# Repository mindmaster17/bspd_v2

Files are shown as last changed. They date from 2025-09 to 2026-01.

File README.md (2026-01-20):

# Team Petronarc GECT
# bspd_v1
# BSPD_V1 — Brake System Plausibility Device (Formula Imperial CV)

This repository contains the circuit design, schematics, and documentation for **BSPD_V1**, a low-cost and rule-compliant Brake System Plausibility Device (BSPD) designed for **Formula Imperial Combustion (CV)** vehicles using **mechanical throttle**.

---
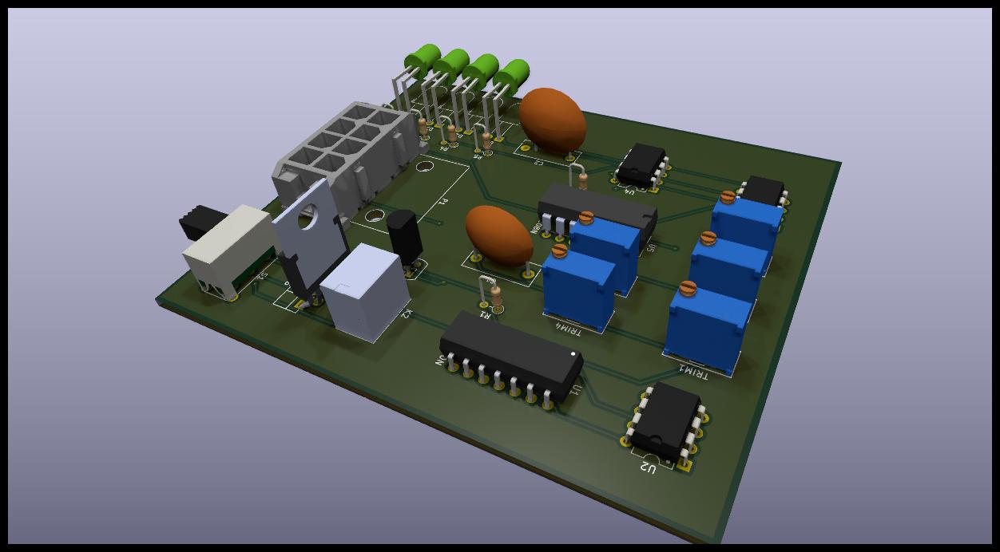
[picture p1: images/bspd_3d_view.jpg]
BSPD 3D View
|  | 3D view of the BSPD PCB assembly (component placement & enclosure layout) |

##  Overview

The **Brake System Plausibility Device (BSPD)** monitors the **Throttle Position Sensor (TPS)** and **Brake Pressure Sensor (BPS)** to detect unsafe driving conditions — specifically, **when the throttle is open beyond a limit while the brake is applied**.

If such a condition persists for more than a preset time (≈500 ms), the BSPD **opens the shutdown circuit**, cutting engine power (via the fuel pump or ECU relay).

This design follows the **Formula Imperial 2025 Rulebook (E.2.9)** guidelines for CV vehicles.

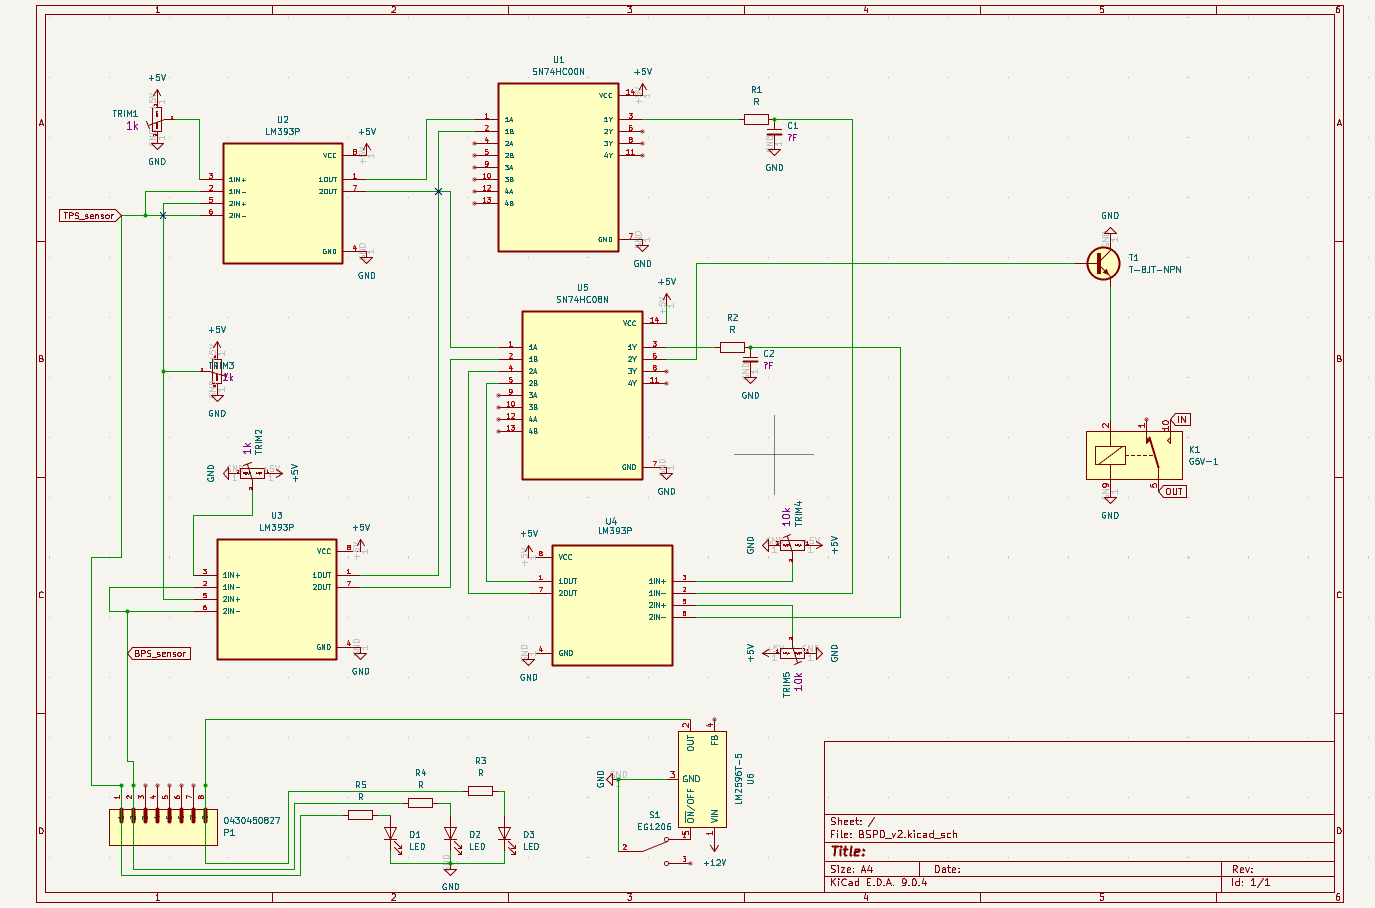
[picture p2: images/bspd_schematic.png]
BSPD Schematic Diagram
|  | Electrical schematic showing comparators, thresholds, latch, and relay driver stages |
---

##  Key Features

- ✅ **2 Analog Inputs** — Throttle (0–5 V) and Brake (0–5 V or 0–10 V)
- ✅ **Adjustable Thresholds** for both BPS and TPS (via onboard potentiometers)
- ✅ **Plausibility Delay:** ~0.5 s (adjustable via RC network)
- ✅ **Latch on Fault:** Once tripped, BSPD remains in fault state until the **Primary Master Switch (PMS)** is cycled
- ✅ **Onboard Indicators:** LEDs for Brake threshold, Throttle threshold, and Fault
- ✅ **12 V operation (8–24 V range)** with onboard 5 V regulation
- ✅ **Fail-Safe Relay Output:** Normally Closed (NC) relay for shutdown loop

---

## 🧩 How It Works

1. **TPS Comparator** checks if throttle > 10% (or > set threshold).
2. **BPS Comparator** checks if brake > set pressure (typically ≥ 30 bar).
3. Both outputs go into a **NOR gate** — if both are HIGH (throttle + brake), output triggers fault.
4. A **delay comparator (≈500 ms)** ensures it’s not a false transient.
5. **Relay driver** drops the shutdown loop (fuel pump / ECU power).
6. BSPD stays tripped until **PMS is turned OFF → ON**.

---

## 🪛 Modifications (for FI 2025 Compliance)

| Issue | Action Taken | Rule Reference |
|---|---|---|
| Auto reset after 10 s (non-compliant) | Disabled RC network (R12–C7) | FI E.2.9.5 |
| Cockpit reset not allowed | Only resets via PMS cycle | FI E.2.9.6 |
| Power always ON | BSPD powered only from PMS-switched 12 V line | FI E.2.9 |
| Plausibility logic | Verified 0.45 V – 5 V window check and 500 ms delay | FI E.2.9 |

---

## 🧰 Components

| Component | Value | Description |
|---|---|---|
| LM393 | Dual comparator | Plausibility & fault logic |
| LM7805 / LM2596 | Regulator | 12 V → 5 V logic supply |
| R12 | 100 kΩ | *Removed* to disable auto-reset |
| C7 | 100 µF | *Removed* or open-circuited |
| Relay | 12 V, SPDT, NC used for shutdown loop | Fuel/ECU cutoff |
| LEDs | — | Fault, TPS threshold, BPS threshold indicators |

---

## ⚡ Power & Wiring

```text
Battery +  → Primary Master Switch (PMS)  → Fuse  → BSPD +12 V  → Fuel Pump Relay Coil → ECU

BSPD Signal Output  →  Controls Shutdown Relay  → In series with Fuel Pump or ECU power

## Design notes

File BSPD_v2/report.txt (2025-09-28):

Warning: Width correction constrained.  The width correction value must be in the range of [0.000001 mm; 0.199999 mm] for the current design rules.
Plotted to 'C:\Users\navad\Desktop\SUPRA\bspd_v2\BSPD_v2\Gerber\BSPD_v2-F_Cu.gbr'.
Plotted to 'C:\Users\navad\Desktop\SUPRA\bspd_v2\BSPD_v2\Gerber\BSPD_v2-B_Cu.gbr'.
Plotted to 'C:\Users\navad\Desktop\SUPRA\bspd_v2\BSPD_v2\Gerber\BSPD_v2-F_Paste.gbr'.
Plotted to 'C:\Users\navad\Desktop\SUPRA\bspd_v2\BSPD_v2\Gerber\BSPD_v2-B_Paste.gbr'.
Plotted to 'C:\Users\navad\Desktop\SUPRA\bspd_v2\BSPD_v2\Gerber\BSPD_v2-F_Silkscreen.gbr'.
Plotted to 'C:\Users\navad\Desktop\SUPRA\bspd_v2\BSPD_v2\Gerber\BSPD_v2-B_Silkscreen.gbr'.
Plotted to 'C:\Users\navad\Desktop\SUPRA\bspd_v2\BSPD_v2\Gerber\BSPD_v2-F_Mask.gbr'.
Plotted to 'C:\Users\navad\Desktop\SUPRA\bspd_v2\BSPD_v2\Gerber\BSPD_v2-B_Mask.gbr'.
Plotted to 'C:\Users\navad\Desktop\SUPRA\bspd_v2\BSPD_v2\Gerber\BSPD_v2-Edge_Cuts.gbr'.
Created Gerber job file 'C:\Users\navad\Desktop\SUPRA\bspd_v2\BSPD_v2\Gerber\BSPD_v2-job.gbrjob'.
Info: Done.
Info: Done.

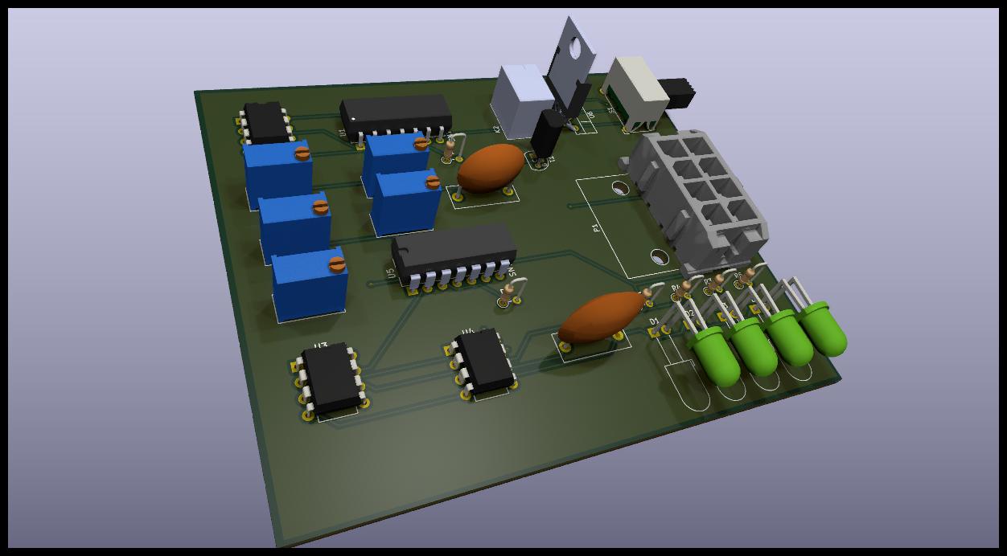
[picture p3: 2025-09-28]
images/BSPD_v2.jpg

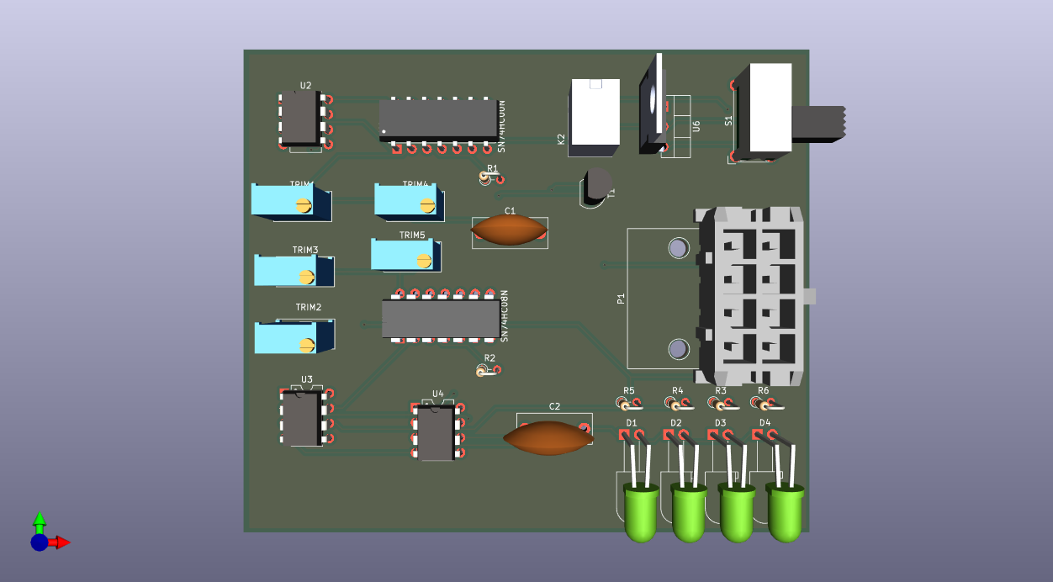
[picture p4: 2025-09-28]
images/BSPD_v2.png

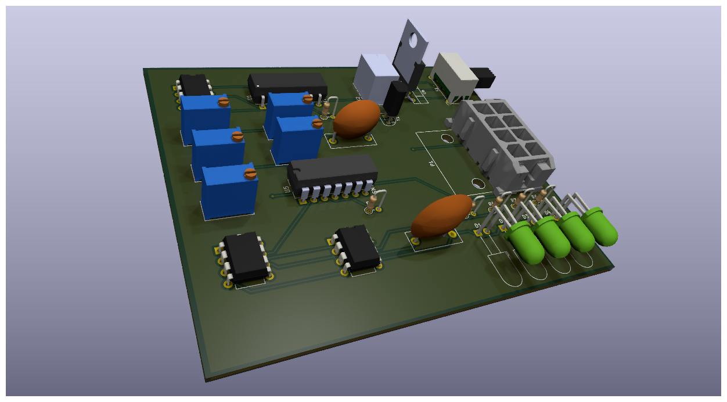
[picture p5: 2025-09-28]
BSPD_v2/BSPD_v2.png

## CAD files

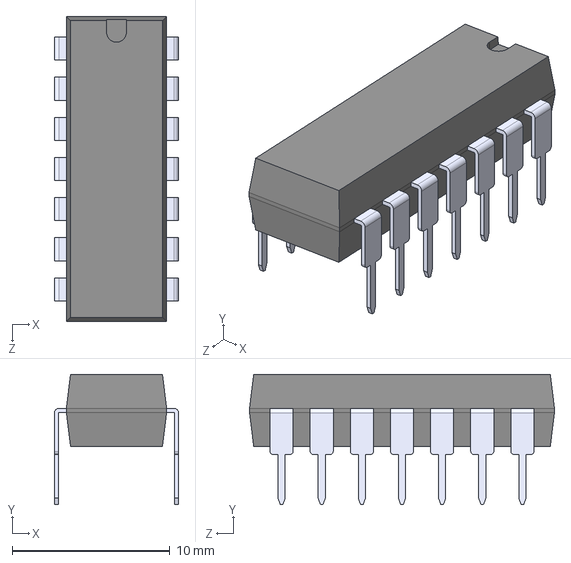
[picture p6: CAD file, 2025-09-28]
BSPD_v2/7400(NAND)/SN74HC00N.STEP
7.87 x 8.26 x 19.3 mm

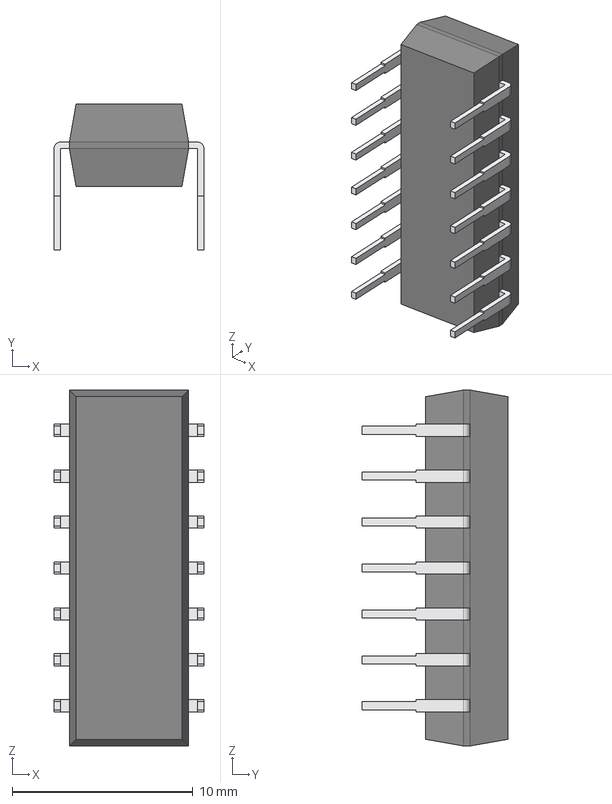
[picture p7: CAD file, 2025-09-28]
BSPD_v2/7400(NAND)/SN74HC00N/SN74HC00N.step
8.29 x 8.08 x 19.7 mm
Body001 (Mirror #1) x 8

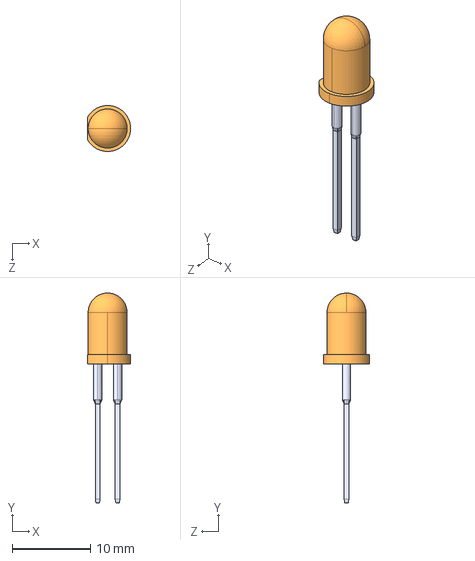
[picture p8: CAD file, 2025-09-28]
BSPD_v2/LED/L08R5000Q1--3DModel-STEP-56544.STEP
5.55 x 26.9 x 5.90 mm

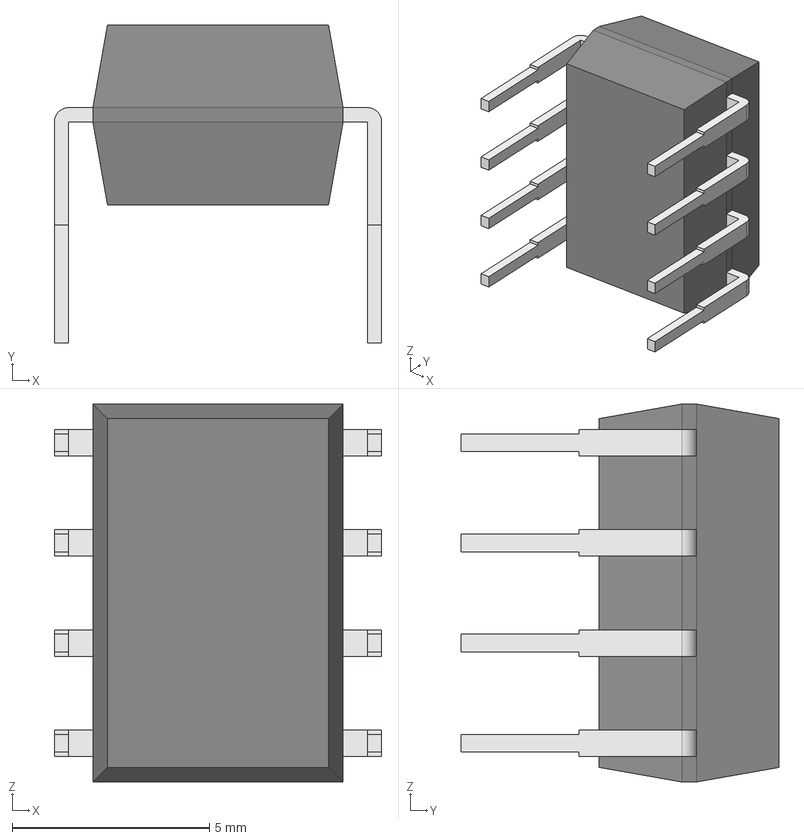
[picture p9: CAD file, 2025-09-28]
BSPD_v2/lm393/LM393P.STEP
8.31 x 8.08 x 9.59 mm
Body001 (Mirror #1) x 5

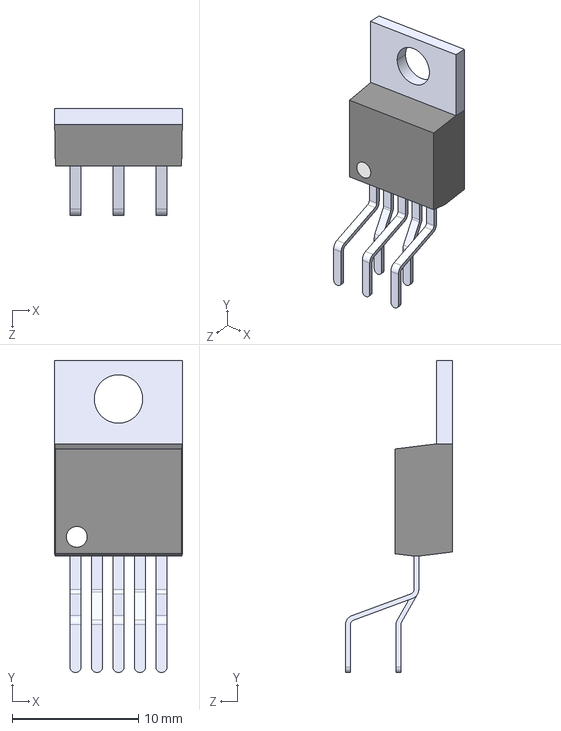
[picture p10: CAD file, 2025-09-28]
BSPD_v2/Regulator/LM2596T-5.0/LM2596T-5.0.step
10.2 x 24.7 x 8.47 mm

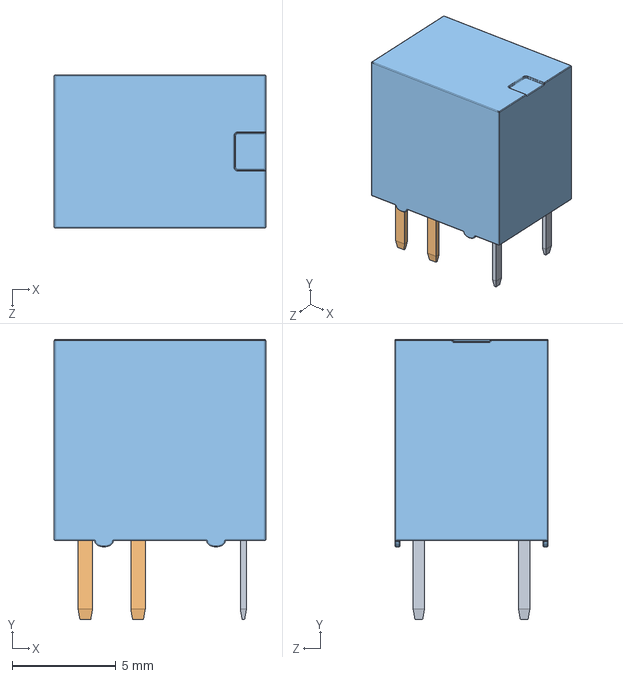
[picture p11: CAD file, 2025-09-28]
BSPD_v2/Relay/SR1-5V-450-1C--3DModel-STEP-1.STEP
10.2 x 13.5 x 7.40 mm

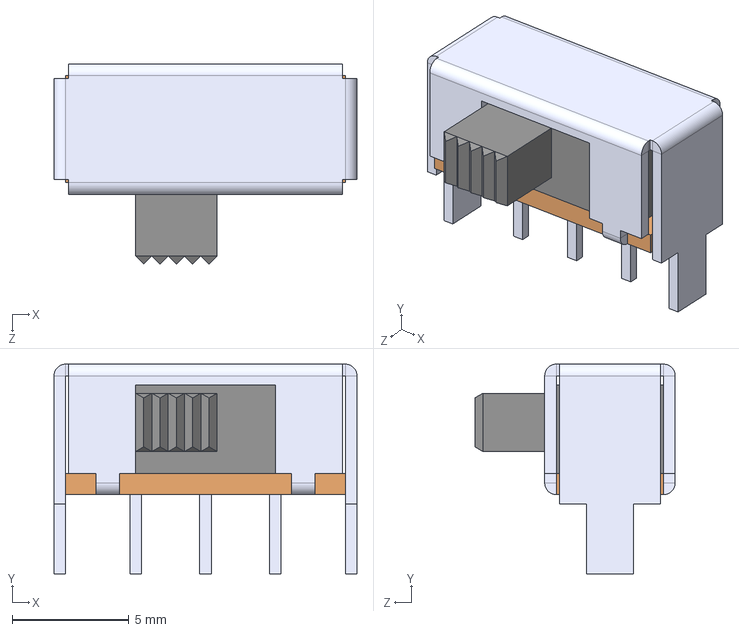
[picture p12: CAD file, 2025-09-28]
BSPD_v2/Switch/EG1206--3DModel-STEP-418109.STEP
13.0 x 9.00 x 8.60 mm

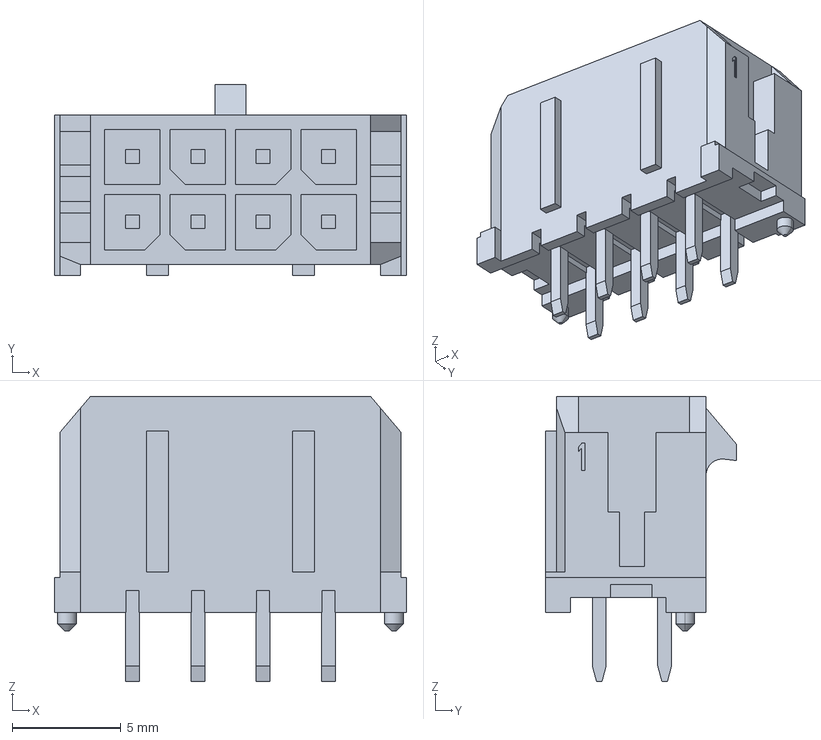
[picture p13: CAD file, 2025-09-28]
BSPD_v2/Molex_connector/0430450827/0430450827.step
16.1 x 8.77 x 13.1 mm

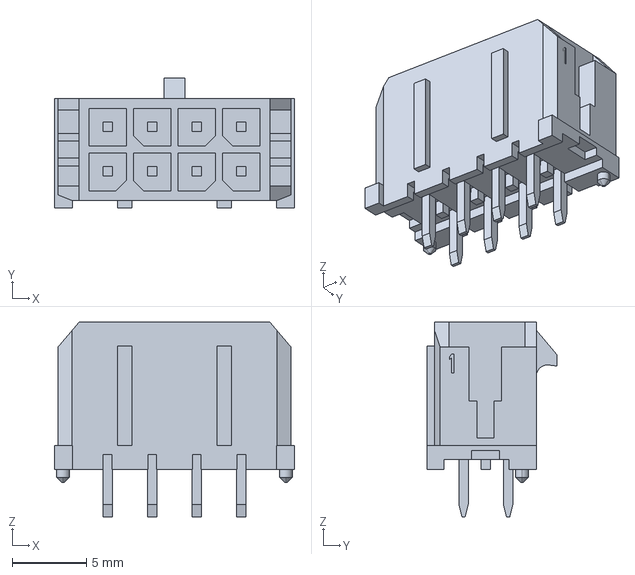
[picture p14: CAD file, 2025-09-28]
BSPD_v2/Molex_connector/171323564-659-0430450827/0430450827.stp
16.1 x 8.77 x 13.1 mm

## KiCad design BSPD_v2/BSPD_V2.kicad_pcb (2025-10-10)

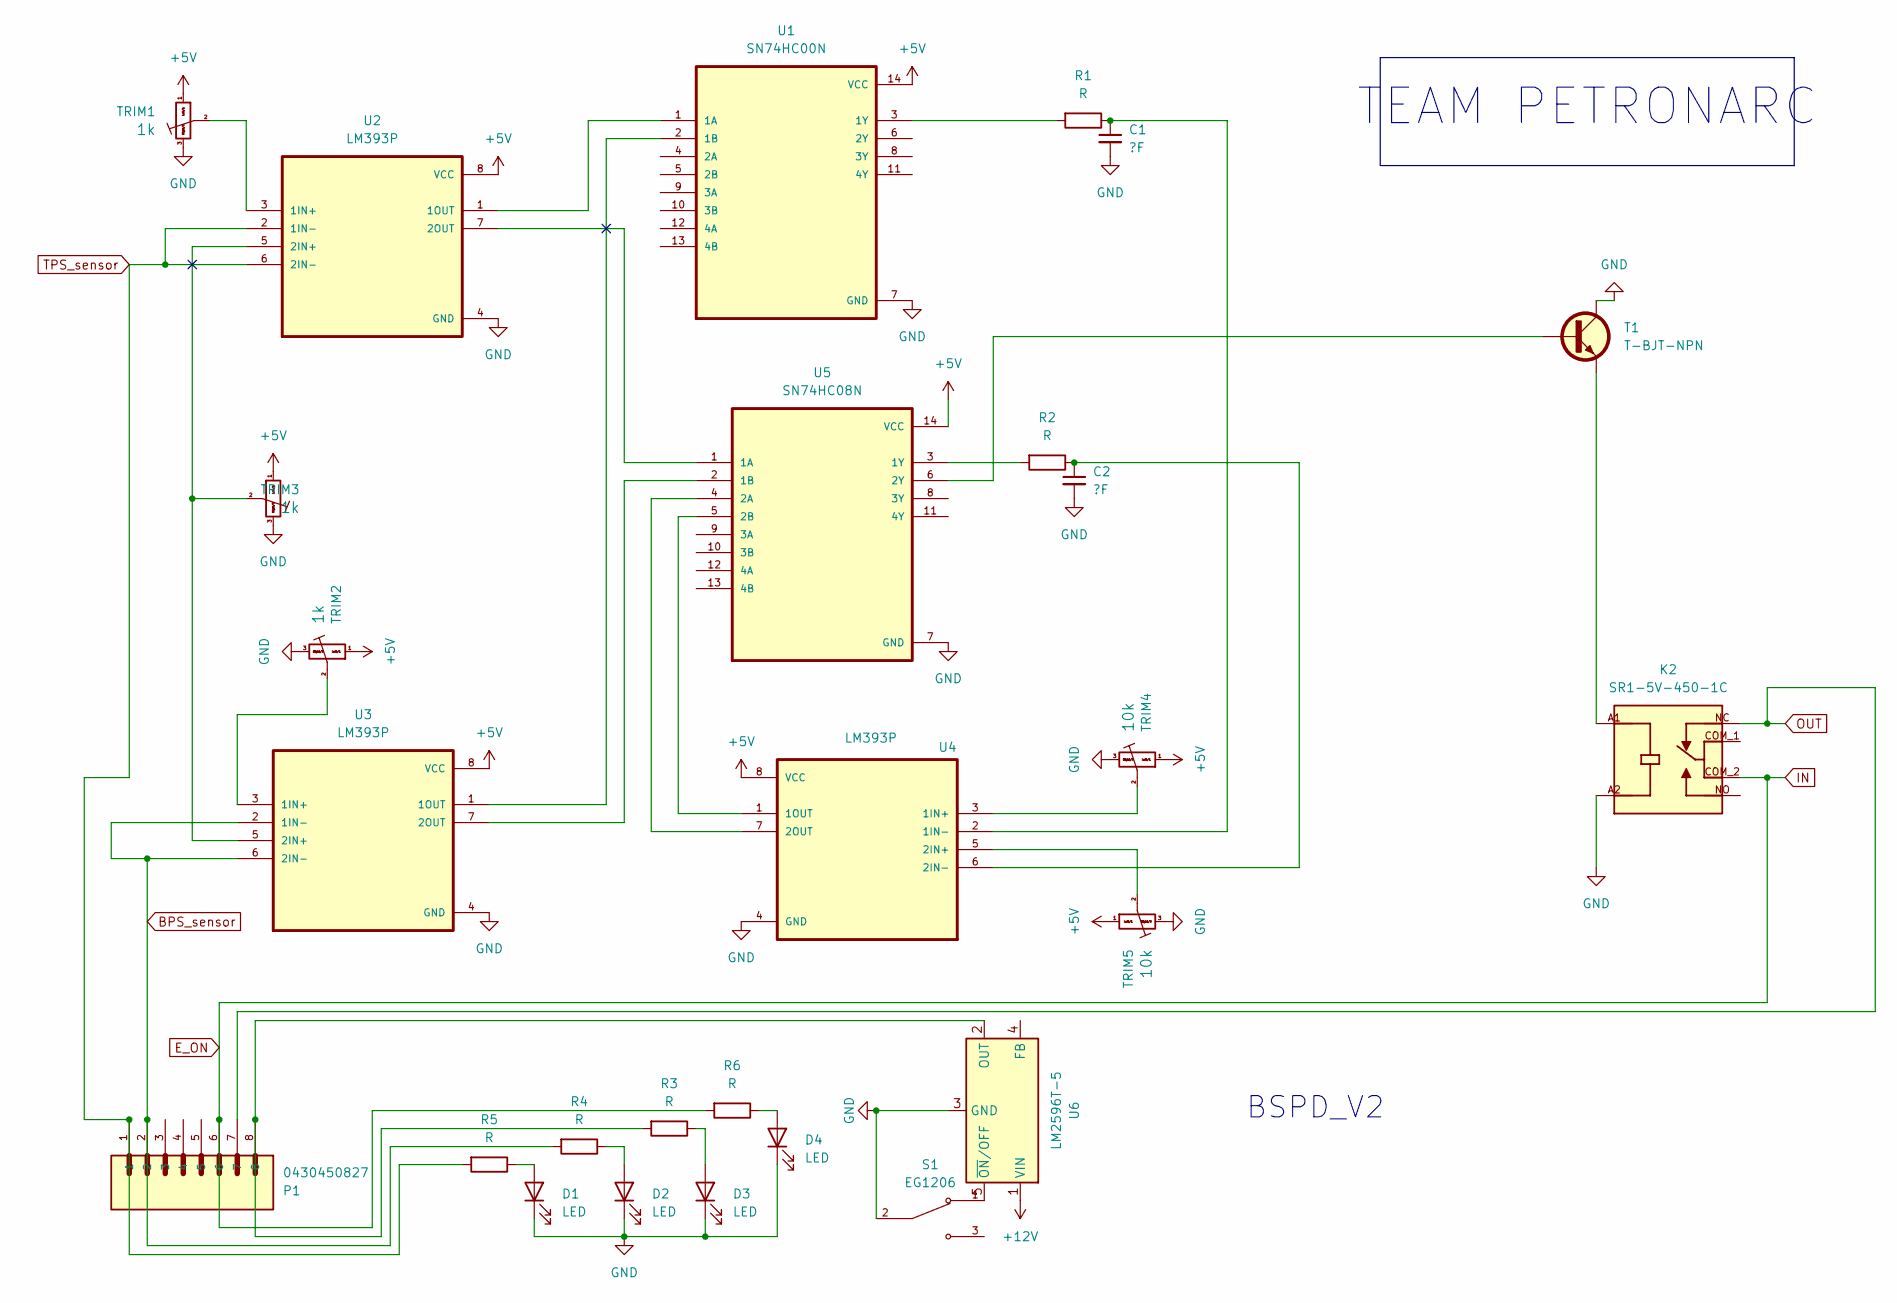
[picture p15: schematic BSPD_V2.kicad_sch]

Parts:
C1, C2: C_Generic; C_Disc_D12.5mm_W5.0mm_P10.00mm
D1, D2, D3, D4: LED; LED_D5.0mm_Horizontal_O6.35mm_Z9.0mm
K2: SR1-5V-450-1C; RELAY_SR1-5V-450-1C; PARTREV 1.01; DigiKey_Part_Number 2223-SR1-5V-450-1C-ND
P1: 0430450827; Molex_Mega-Fit_76825-0008_2x04_P5.70mm_Horizontal
R1, R2, R3, R4, R5, R6: R; R_Axial_DIN0204_L3.6mm_D1.6mm_P2.54mm_Vertical
S1: EG1206; SW_E-Switch_EG1224_SPDT_Angled; PARTREV B
T1: T-BJT-NPN; TO-92L_ECB
TRIM1: TrimPot_TC33X_1k; Potentiometer_Bourns_3296W_Vertical; Part Number TC33X-2-102G
TRIM2, TRIM3: TrimPot_T73YEt_1k; Potentiometer_Bourns_3296W_Vertical; Part Number T73YE102KT20
TRIM4, TRIM5: TrimPot_T73YEt_10k; Potentiometer_Bourns_3296W_Vertical; Part Number T73YE102KT20
U1: SN74HC00N; DIP-14_W7.62mm
U2, U3, U4: LM393P; DIP-8_W7.62mm
U5: SN74HC08N; DIP-14_W7.62mm; DigiKey_Part_Number 2156-SN74HC08N-ND
U6: LM2596T-5; TO-220F-5_P3.4x2.06mm_StaggerEven_Lead1.86mm_Vertical

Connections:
+5V: TRIM1.1 (Left), TRIM2.1 (Left), TRIM3.1 (Left), TRIM4.1 (Left), TRIM5.1 (Left), U1.14 (VCC), U2.8 (VCC), U3.8 (VCC), U4.8 (VCC), U5.14 (VCC)
+12V: U6.1 (VIN)
BPS_sensor: P1.2, R4.2, U3.2 (1IN-), U3.6 (2IN-)
E_ON: K2.COM_2, P1.6, R6.2
GND: C1.2, C2.2, D1.1 (K), D2.1 (K), D3.1 (K), D4.1 (K), K2.A2, S1.2, T1.1 (C), TRIM1.3 (Right), TRIM2.3 (Right), TRIM3.3 (Right), TRIM4.3 (Right), TRIM5.3 (Right), U1.7 (GND), U2.4 (GND), U3.4 (GND), U4.4 (GND), U5.7 (GND), U6.3 (GND)
unnamed: D1.2 (A), R5.1
unnamed: D2.2 (A), R4.1
unnamed: D3.2 (A), R3.1
unnamed: D4.2 (A), R6.1
unnamed: T1.2 (B), U5.6 (2Y)
unnamed: K2.A1, T1.3 (E)
unnamed: TRIM1.2 (Center), U2.3 (1IN+)
unnamed: TRIM2.2 (Center), U3.3 (1IN+)
unnamed: TRIM3.2 (Center), U2.5 (2IN+), U3.5 (2IN+)
unnamed: TRIM4.2 (Center), U4.3 (1IN+)
unnamed: TRIM5.2 (Center), U4.5 (2IN+)
unnamed: U1.1 (1A), U2.1 (1OUT)
unnamed: U1.2 (1B), U3.1 (1OUT)
unnamed: R1.2, U1.3 (1Y)
unnamed: U2.7 (2OUT), U5.1 (1A)
unnamed: U3.7 (2OUT), U5.2 (1B)
unnamed: C1.1, R1.1, U4.2 (1IN-)
unnamed: U4.1 (1OUT), U5.5 (2B)
unnamed: C2.1, R2.1, U4.6 (2IN-)
unnamed: U4.7 (2OUT), U5.4 (2A)
unnamed: R2.2, U5.3 (1Y)
unnamed: P1.8, R3.2, U6.2 (OUT)
unnamed: S1.1, U6.5 (~ON/OFF)
OUT: K2.NC, P1.7
TPS_sensor: P1.1, R5.2, U2.2 (1IN-), U2.6 (2IN-)

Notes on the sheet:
BSPD_V2
TEAM PETRONARC

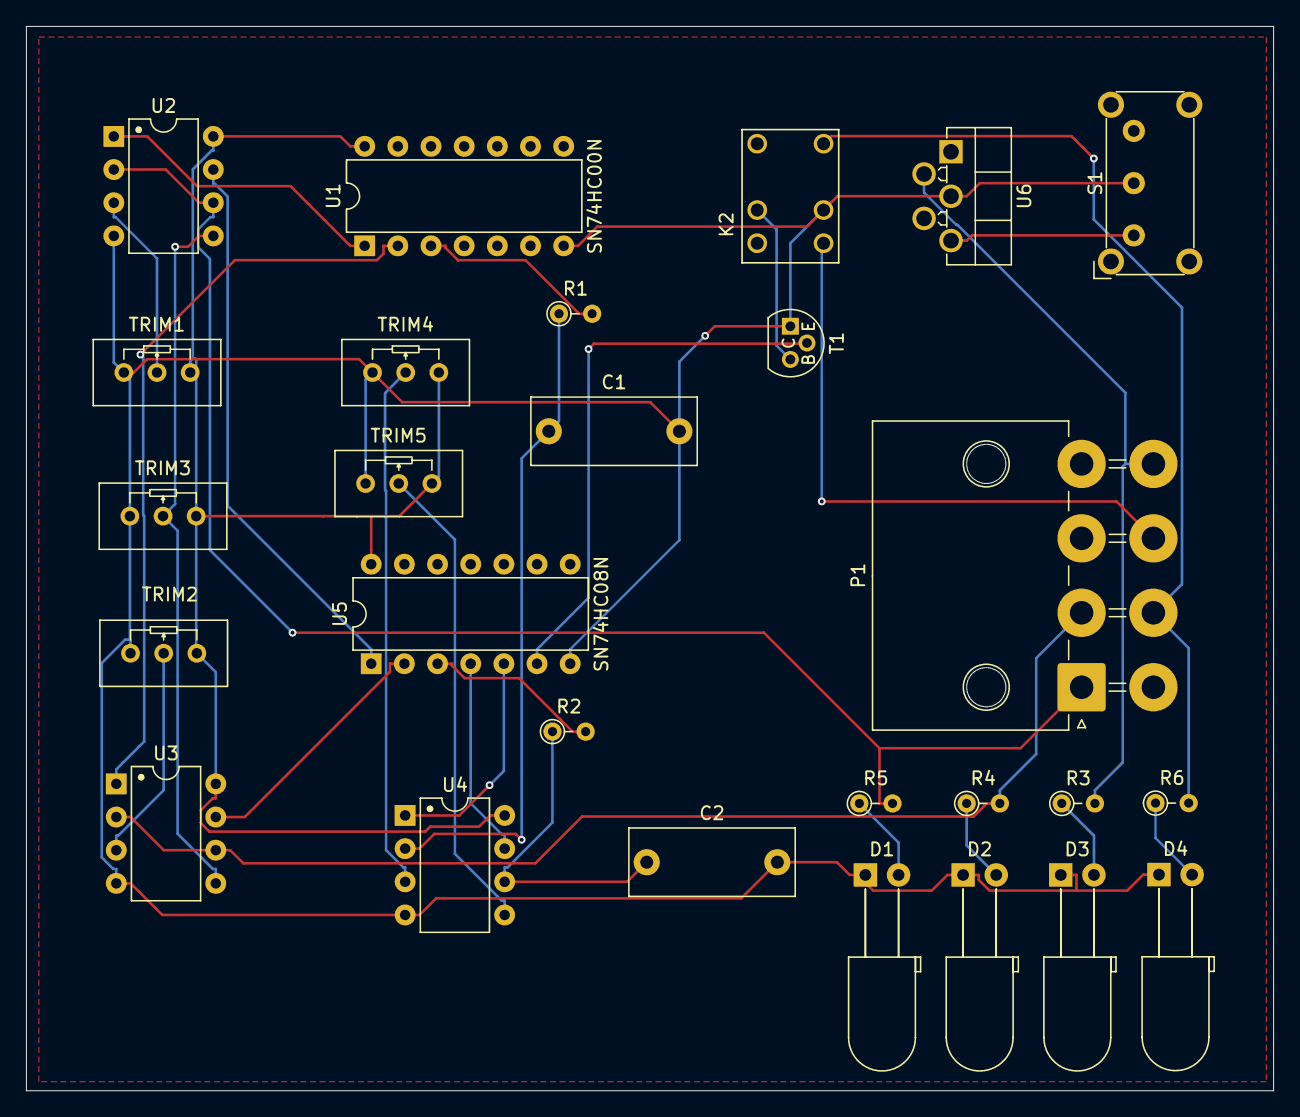
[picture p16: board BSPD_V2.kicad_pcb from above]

Board: 2 copper layers, 95.5 x 81.5 mm, 27 parts (0 on the bottom side), 29 nets.

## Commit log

2025-09-28 updated kicad files
    [0430450827.step, 0430450827.stp, BSPD_V2.kicad_pcb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]
2025-09-28 updated schematic
    [BSPD_V2.kicad_sch, BSPD_v2.1.kicad_sch]
2025-09-28 updated library
    [EG1206--3DModel-STEP-418109.STEP, EG1206.step]
2025-09-28 updated footprints
    [BSPD_V2.kicad_sch]
2025-09-28 Added footprints
    [BSPD_V2.kicad_sch]
2025-09-28 Updated pcb design
    [BSPD_V2.kicad_pcb]
2025-09-28 Updated pcb design with check
    [BSPD_V2.kicad_pcb]
2025-09-28 pcb design updated using proper footprints and routing
    [BSPD_V2.kicad_pcb, BSPD_V2.kicad_sch]
2025-09-28 Added footprints for 5v Regulator
    [BSPD_V2.kicad_pcb, BSPD_V2.kicad_sch, LM2596T-5.0.step]
2025-09-28 pcd updated gerber file created
    [BSPD_V2.kicad_pcb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]
2025-09-29 update BSPD_v2_render
    [BSPD_V2.kicad_pcb]
2026-01-20 Revise README for BSPD_V1 project details
    Updated README to reflect project details for BSPD_V1, including overview, key features, modifications for compliance, components, and wiring.
